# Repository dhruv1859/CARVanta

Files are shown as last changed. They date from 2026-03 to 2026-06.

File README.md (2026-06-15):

<p align="center">
  
</p>

<h1 align="center">🧬 CARVanta</h1>
<h3 align="center">AI-Augmented CAR-T Cell Target Viability Assessment Platform<br>+ Sentinel HYDRA Bedside Biosensor</h3>

<p align="center">
  
  
  
  
  
  
</p>

<p align="center">
  
  
  
  
  
</p>

<p align="center">
  <strong>117,000+ lines of code • 778 source files • 214 Python modules • 45 React pages • 50 firmware files • 6-layer medical PCB</strong>
</p>

---

## 🎯 What is CARVanta?

**CARVanta** is a closed-loop immunotherapy intelligence system — an **AI software platform** connected to a **bedside biosensor device** — that turns CAR-T cell therapy target selection from art into science.

> **The core problem:** Selecting the right antigen target is the most critical decision in CAR-T therapy design. A wrong target leads to years of wasted R&D and patient harm. CARVanta automates this decision with data-driven scoring validated against FDA-approved targets, and monitors treatment in real time to catch antigen escape before it kills.

### Key Capabilities

| Module | Description |
|---|---|
| 🔬 **CVS Scoring Engine** | 8-feature adaptive weighted algorithm with multi-source consensus |
| 🤖 **ML Ensemble** | Random Forest + XGBoost classifier + regression ranker |
| 🧠 **LLM Integration** | Grok/Groq/Gemini/OpenAI for dynamic clinical reasoning |
| 🧬 **Genomic Profiler** | Variant calling, HLA typing, TMB calculation, neoantigen prediction |
| 🧑‍⚕️ **Digital Twin** | Patient-specific CRS/ICANS simulation with pharmacokinetic modeling |
| 📊 **Clinical Trials** | Safety monitoring, DSMB reports, RWE analysis, regulatory intelligence |
| 🔍 **NLP Search** | Natural language antigen discovery with semantic intent detection |
| 🏆 **Model Validation** | 5-fold CV, FDA ground-truth validation, ISO/IEC 25010 certification |
| 🌐 **Neural Bridge** | 3D knowledge graph visualization of antigen-disease relationships |
| 💊 **Drug Discovery** | scFv designer, toxicity prediction, CAR construct architecture |
| 📈 **Deep Learning** | Autoencoder anomaly detection, attention mechanisms, neural scoring |
| 🔬 **Sentinel HYDRA** | Real-time 4-channel antigen monitoring with bedside biosensor hardware |

---

## 🏗️ Architecture

```
Patient blood (fingerprick)
        │
        ▼
┌───────────────────────┐
│   SENTINEL HYDRA      │     Bedside device — 100×100mm, ~$79/unit
│   RP2040 + ESP32-S3   │     6-layer medical PCB, ENIG finish
│                       │
│   • 4× potentiostat   │     Sensor data
│   • SpO2 + heart rate │     ─────────────────►
│   • 11-ch spectral    │          WiFi (TLS)
│   • Impedance + temp  │
└───────────┬───────────┘
            │
            ▼
┌─────────────────────────────────────────────────────────────┐
│                    CARVANTA CLOUD PLATFORM                    │
├─────────────────────────────────────────────────────────────┤
│                    Frontend (React + Vite)                    │
│  45 pages • Clinical Precision UI • Glassmorphism Design     │
├─────────────────────────────────────────────────────────────┤
│                    FastAPI Backend (v5)                       │
│  28 routers • Async • CORS • Rate limiting • Audit logging   │
├──────────┬──────────┬──────────┬──────────┬─────────────────┤
│ Scoring  │    ML    │   LLM    │ Genomics │   Validation    │
│ Engine   │ Ensemble │ Insight  │ Pipeline │   & Certify     │
│ (CVS v3) │ (RF+XGB) │(Grok/AI) │(VCF/HLA)│  (ISO 25010)   │
├──────────┴──────────┴──────────┴──────────┴─────────────────┤
│              Data Layer (SQLite / PostgreSQL)                 │
│        biomarker_database.csv • 500+ scored antigens         │
└─────────────────────────────────────────────────────────────┘
            │
            ▼
  Doctor's phone: "CD19 dropping — antigen escape risk. Switch to CD22."
```

> For a deep dive into the full system architecture, see [ARCHITECTURE.md](ARCHITECTURE.md).

---

## 🔬 Sentinel HYDRA — Bedside Biosensor

The **Sentinel HYDRA** is a credit-card-sized medical-grade device that continuously monitors blood biomarkers through a disposable sensor strip. It detects antigen escape — the #1 reason CAR-T fails — in **30 seconds** instead of days via lab tests.

### Hardware Specifications

| Parameter | Value |
|---|---|
| Dimensions | 100mm × 100mm |
| PCB Layers | **6** (signal/ground/analog/power/high-speed/bottom) |
| MCUs | **ESP32-S3** (main) + **RP2040** (sensor coprocessor) |
| Antigen Channels | **4 simultaneous** (CD19, CD22, BCMA, GPRC5D) |
| ADC | ADS1256 — **24-bit**, 8-channel, 30kSPS |
| Potentiostat | 4× LMP91000 (one per antigen channel) |
| SpO2/Heart Rate | MAX30102 integrated sensor |
| Spectral | AS7341 — **11 wavelength channels** |
| Temperature | TMP117 (±0.1°C) + MLX90614 (contactless IR) |
| IMU | LSM6DSO — 6-axis (fall detection) |
| Display | 2.4" IPS TFT (320×240, ST7789) |
| Connectivity | WiFi + BLE (ESP32-S3) |
| Data Logging | microSD + DS3231 RTC |
| Power | USB-C + LiPo battery (BQ24075 charger) |
| Surface Finish | ENIG (immersion gold) — biocompatible |
| Cost per Unit | **~$79** (complete with battery + display + sensor) |

### Manufacturing Files

Production-ready Gerber files for PCB fabrication are available:

📦 **[Sentinel_HYDRA_Gerbers.zip](hardware/sentinel/kicad/Sentinel_HYDRA/Sentinel_HYDRA_Gerbers.zip)** — Upload directly to JLCPCB / PCBWay

Contains:
- 6 copper layers (Digital_Signals, GND_Plane, Analog_Signals, Power_Planes, HighSpeed, Bottom_GND)
- Front/Back solder mask, silkscreen, paste stencil
- Board outline (Edge.Cuts)
- Excellon drill files (PTH + NPTH separated)
- Drill map files
- Gerber job file

> For the full Bill of Materials, see [BOM.md](hardware/sentinel/BOM.md).

---

## 🚀 Quick Start

### Prerequisites

- Python 3.12+
- Node.js 18+
- Git

### 1. Clone & Setup

```bash
git clone https://github.com/dhruv1859/CARVanta.git
cd CARVanta

# Backend
pip install -r requirements.txt
copy .env.example .env
# Edit .env — add your XAI_API_KEY or GROQ_API_KEY for LLM features

# Frontend
cd frontend-react
npm install
```

### 2. Run Locally

```bash
# Terminal 1 — Backend
py -m uvicorn api.main:app --host 0.0.0.0 --port 8001

# Terminal 2 — Frontend
cd frontend-react
npm run dev
```

Open **http://localhost:5173** → full platform is live.

### 3. Train ML Models (Optional)

```bash
py models/train_pipeline.py
```

This runs 5-fold stratified cross-validation and trains the RF+XGBoost ensemble + regression ranker.

### 4. Build Firmware (Optional)

Requires [PlatformIO](https://platformio.org/install):

```bash
# ESP32 main controller
cd hardware/sentinel/firmware/esp32_hydra
pio run

# RP2040 sensor coprocessor
cd hardware/sentinel/firmware/rp2040_hydra
pio run
```

---

## 🧪 Scoring Algorithm

### CVS (CAR-T Viability Score) v3

CARVanta's **original** 8-feature Adaptive Weighted Scoring:

| Feature | Weight | Source |
|---|---|---|
| Tumor Specificity | 25% | TCGA differential expression |
| Safety Score | 20% | GTEx normal tissue risk (inverted) |
| Stability | 12% | Expression consistency |
| Evidence | 10% | Published clinical support |
| Immunogenicity | 10% | Immune recognition potential |
| Surface Accessibility | 8% | UniProt/HPA membrane localization |
| Tissue Risk | 8% | GTEx organ-level heatmap |
| Protein Validation | 7% | HPA protein-level confirmation |

**Adaptive Weight Adjustment:** When real data sources (TCGA, GTEx, HPA) are available, feature weights dynamically shift to give more credence to features backed by real data vs. estimated values.

### ML Ensemble (v4)

The final score blends rule-based CVS with ML predictions:

```
Adaptive Score = (1 - α) × CVS + α × ML_score
```

Where `α` is dynamically adjusted based on data confidence (range: 0.20–0.40).

---

## 🏆 Model Validation & Certification

CARVanta includes a **production-grade validation suite** aligned with ISO/IEC 25010:

| Test | Method | What It Proves |
|---|---|---|
| **Classifier CV** | 5-fold Stratified K-Fold | Accuracy, F1, AUC-ROC, Precision, Recall |
| **Ranker CV** | 5-fold K-Fold Regression | R², MAE, RMSE, Spearman ρ |
| **FDA Ground-Truth** | CD19, BCMA, CD22, GPRC5D | All approved targets must score Tier 1 |
| **Negative Controls** | TP53, RB1, BRCA1, PTEN, APC | Non-viable targets rejected correctly |
| **Robustness** | ±5% feature perturbation | Measures prediction stability |
| **Statistical Significance** | Paired t-test + Wilcoxon | Model vs. 3 random baselines (p < 0.01) |
| **Calibration** | Brier score + log loss | Probability reliability |

Run validation: `GET /api/v5/validation/run`

---

## 🤖 LLM Integration

CARVanta uses LLMs to generate **dynamic clinical reasoning** instead of hardcoded insights:

- **Supported Providers:** Grok (xAI) → Groq → DeepSeek → Gemini → OpenAI
- **Fallback:** If no LLM key is configured, rule-based insights are served
- **Provenance:** Every AI insight displays a badge showing `🤖 LLM Generated` or `📐 Rule-Based`

Set one key in `.env`:
```
XAI_API_KEY=your-grok-key
# or
GROQ_API_KEY=your-groq-key
```

---

## ☁️ Deploy to Railway

### One-Click Deploy

1. Go to [railway.app](https://railway.app) → **New Project** → **Deploy from GitHub repo**
2. Select `dhruv1859/CARVanta`
3. Railway auto-detects `nixpacks.toml` and builds
4. Add environment variables in Railway dashboard:

| Variable | Required | Description |
|---|---|---|
| `XAI_API_KEY` | ✅ | Grok API key for LLM insights |
| `CARVANTA_ENV` | Optional | Set to `production` |
| `DATABASE_URL` | Optional | PostgreSQL URL (defaults to SQLite) |

5. Railway assigns a public URL → your API is live

### Frontend Deployment

Deploy the React frontend separately on **Vercel** or **Netlify**:

```bash
cd frontend-react
npm run build
# Upload dist/ to Vercel/Netlify
# Set VITE_API_URL to your Railway backend URL
```

---

## 📁 Project Structure

```
CARVanta/
├── api/                        # 28 FastAPI routers (v5)
│   ├── main.py                 # App entrypoint
│   ├── auth.py                 # JWT authentication
│   ├── validation_router.py    # Model validation endpoints
│   └── ...
├── scoring/                    # CVS scoring engine (v3)
├── models/                     # ML pipeline (RF + XGBoost)
├── features/                   # Feature engineering + LLM + FHIR
├── validation/                 # Model validation & certification
├── deep_learning/              # Autoencoder, attention, neural models
├── genomics/                   # Variant calling, HLA, TMB
├── digital_twin/               # Patient simulation engine
├── discovery/                  # Drug discovery, scFv design
├── copilot/                    # Research assistant, RAG engine
├── trials/                     # Clinical trial intelligence
├── frontend-react/             # React 18 + Vite + TypeScript
│   └── src/pages/              # 45 page modules
├── hardware/
│   └── sentinel/
│       ├── kicad/
│       │   └── Sentinel_HYDRA/         # 6-layer KiCad PCB project
│       │       ├── *.kicad_sch         # 7 schematic sheets
│       │       ├── Sentinel_HYDRA.kicad_pcb
│       │       ├── gerbers/            # Production Gerber files
│       │       └── Sentinel_HYDRA_Gerbers.zip
│       ├── firmware/
│       │   ├── esp32_hydra/            # ESP32-S3 firmware (50 files)
│       │   └── rp2040_hydra/           # RP2040 firmware
│       ├── BOM.md                      # Bill of materials (~$79/unit)
│       └── README.md                   # Hardware documentation
├── data/                       # Biomarker database + reports
├── ARCHITECTURE.md             # Full system architecture
├── nixpacks.toml               # Railway deployment config
├── railway.json                # Railway service config
└── requirements.txt            # Python dependencies
```

---

## 🔑 API Endpoints

### Core Scoring
| Endpoint | Method | Description |
|---|---|---|
| `/api/v5/score` | POST | Score a single antigen |
| `/api/v5/batch_score` | POST | Score multiple antigens |
| `/api/v5/rankings` | GET | Global antigen leaderboard |
| `/api/v5/nlp/query` | POST | Natural language search |

### Validation
| Endpoint | Method | Description |
|---|---|---|
| `/api/v5/validation/run` | GET | Full validation suite |
| `/api/v5/validation/quick` | GET | Quick classifier + FDA check |
| `/api/v5/validation/fda-targets` | GET | FDA ground-truth only |
| `/api/v5/validation/certification` | GET | ISO/IEC 25010 report |

### Clinical
| Endpoint | Method | Description |
|---|---|---|
| `/api/v5/digital-twin/simulate` | POST | Patient simulation |
| `/api/v5/trials/clinical-trials` | GET | Trial lookup by antigen |
| `/api/v5/genomics/analyze-variants` | POST | Genomic variant analysis |

Full API docs: `http://localhost:8001/docs` (Swagger UI)

---

## 🛡️ Security & Compliance

- **ISO/IEC 25010** aligned model validation and certification
- **FDA 21 CFR Part 11** concepts for electronic records
- **GAMP 5** risk-based approach compliance framework
- **LLM Provenance** — all AI outputs labeled with origin (LLM vs Rule-Based)
- **Audit Logging** — all scoring requests logged with timestamps
- **CORS + Rate Limiting** middleware (configurable)

See [security.md](security.md) for vulnerability reporting and [PRIVACY_POLICY.md](PRIVACY_POLICY.md) for HIPAA alignment.

---

## 📄 Documentation

| Document | Description |
|---|---|
| [ARCHITECTURE.md](ARCHITECTURE.md) | Full system architecture (software + hardware + firmware) |
| [BOM.md](hardware/sentinel/BOM.md) | Sentinel HYDRA bill of materials |
| [ROADMAP.md](ROADMAP.md) | Product roadmap and future plans |
| [MODULES.md](MODULES.md) | Module registry and build order |
| [CHANGELOG.md](CHANGELOG.md) | Version history |
| [contributing.md](contributing.md) | Contribution guidelines |
| [security.md](security.md) | Security policy |
| [CODE_OF_CONDUCT.md](CODE_OF_CONDUCT.md) | Community code of conduct |
| [MODEL_CARD.md](MODEL_CARD.md) | ML model documentation |
| [ISO_13485_ALIGNMENT.md](ISO_13485_ALIGNMENT.md) | Quality management alignment |
| [PRIVACY_POLICY.md](PRIVACY_POLICY.md) | HIPAA compliance disclosure |

---

## 📄 License

Business Source License 1.1 (BUSL-1.1). See [LICENSE](LICENSE) for details.

---

## 👨‍💻 Author

**Dhruv** — [@dhruv1859](https://github.com/dhruv1859)

---

<p align="center">
  <strong>CARVanta</strong> — Turning immunotherapy target selection from art into science.
</p>

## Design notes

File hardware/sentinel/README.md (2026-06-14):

# CARVanta Sentinel v2.0 — 6-Layer Medical-Grade PCB
## Multi-Channel Antigen Escape Detection System

### Why 6 Layers?

This board monitors **4 antigens simultaneously** (CD19, CD22, BCMA, GPRC5D),
meaning 4 independent electrochemical channels that MUST be electrically isolated
from each other and from the digital noise of the ESP32 + WiFi radio.

A 2-layer board cannot achieve this. Here's why each layer exists:

```
Layer 1 (F.Cu)  — Digital signals: SPI, I2C, UART, USB, GPIO
Layer 2 (GND)   — Continuous ground plane (EMI shield between digital & analog)
Layer 3 (INNER1)— Analog signals: 4× potentiostat outputs, ADC inputs, sensor traces
Layer 4 (PWR)   — Power planes: 3.3V_DIGITAL, 3.3V_ANALOG, 1.8V_CORE, VBAT
Layer 5 (INNER2)— High-speed: USB 2.0 differential pair, WiFi RF routing
Layer 6 (B.Cu)  — Component pads, ground pour, thermal relief
```

### Board Specifications

| Parameter | v1.0 (old) | v2.0 (new) |
|---|---|---|
| Dimensions | 80×55mm | 95×65mm |
| Layers | 2 | **6** |
| Channels | 1 antigen | **4 simultaneous** |
| ADC | 1× ADS1115 (16-bit) | **1× ADS1256 (24-bit, 8ch)** |
| Potentiostat | 1× LMP91000 | **4× LMP91000** |
| Power domains | 1 (3.3V) | **4 (3.3V_D, 3.3V_A, 1.8V, VBAT)** |
| Analog isolation | None | **Split ground plane + ferrite bead** |
| Data logging | None | **microSD + RTC** |
| Patient vitals | None | **MAX30102 SpO2/HR + MLX90614 temp** |
| Impedance control | No | **90Ω USB, 50Ω RF** |
| ESD protection | No | **TVS diodes on all I/O** |
| Cost per unit | $17 | **~$45-55** |

### Stackup (6-Layer, 1.6mm FR4)

```
┌─────────────────────────────────────────────────────────┐
│ Layer 1: F.Cu (Signal - Digital)          35µm copper   │
│   └─ SPI bus, I2C bus, UART, GPIO, LED data            │
├─────────────────────────────────────────────────────────┤
│ Prepreg: 0.2mm FR4 (εr=4.5)                            │
├─────────────────────────────────────────────────────────┤
│ Layer 2: GND (Solid Ground Plane)         35µm copper   │
│   └─ Continuous pour, NO cuts, NO traces                │
│   └─ Acts as EMI shield between digital L1 & analog L3 │
├─────────────────────────────────────────────────────────┤
│ Core: 0.36mm FR4                                        │
├─────────────────────────────────────────────────────────┤
│ Layer 3: INNER1 (Signal - Analog)         35µm copper   │
│   └─ 4× LMP91000 VOUT traces (guarded)                 │
│   └─ ADS1256 analog inputs (star routing)               │
│   └─ Sensor connector traces (kelvin connection)        │
├─────────────────────────────────────────────────────────┤
│ Prepreg: 0.2mm FR4                                      │
├─────────────────────────────────────────────────────────┤
│ Layer 4: PWR (Power Planes)               35µm copper   │
│   └─ Zone 1: 3.3V_DIGITAL (ESP32, TFT, LEDs)          │
│   └─ Zone 2: 3.3V_ANALOG (LMP91000s, ADS1256)         │
│   └─ Zone 3: VBAT (battery direct)                      │
│   └─ Zone 4: 1.8V (ESP32 core, if needed)              │
├─────────────────────────────────────────────────────────┤
│ Core: 0.36mm FR4                                        │
├─────────────────────────────────────────────────────────┤
│ Layer 5: INNER2 (High-Speed Signals)      35µm copper   │
│   └─ USB D+/D- differential pair (90Ω impedance)       │
│   └─ ESP32 antenna feed (50Ω microstrip)                │
│   └─ SD card high-speed data lines                      │
├─────────────────────────────────────────────────────────┤
│ Prepreg: 0.2mm FR4                                      │
├─────────────────────────────────────────────────────────┤
│ Layer 6: B.Cu (Signal + Ground Pour)      35µm copper   │
│   └─ Component pads (bottom-side ICs)                   │
│   └─ Ground pour for thermal dissipation                │
│   └─ Mounting hole connections                          │
└─────────────────────────────────────────────────────────┘
Total thickness: ~1.6mm
```

### Design Rules (Medical Grade)

| Rule | Value | Reason |
|---|---|---|
| Min trace width | 0.15mm (6mil) | JLCPCB 6-layer capability |
| Min clearance | 0.15mm | IPC-2221 Class 2 |
| USB diff pair | 0.18mm trace, 0.15mm gap | 90Ω impedance on L5 |
| Analog traces | 0.25mm, guarded | Noise rejection |
| Power traces | 0.5mm minimum | Current handling |
| Via size | 0.3mm drill, 0.6mm pad | Standard via |
| Via-in-pad | Allowed (filled & capped) | For QFN packages |
| Copper weight | 1oz (35µm) all layers | Standard |
| Surface finish | ENIG (gold) | Corrosion resistance, biocompat |
| Solder mask | Matte black | Premium aesthetic |
| Silkscreen | White, both sides | Component labels |

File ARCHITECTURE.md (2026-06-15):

# CARVanta — System Architecture

> Comprehensive technical architecture of the CARVanta AI Immunotherapy Platform and Sentinel HYDRA biosensor hardware.

---

## System Overview

CARVanta is a **closed-loop immunotherapy intelligence system** comprising two tightly integrated subsystems:

1. **Software Platform** — Cloud-deployed AI engine for antigen target scoring, genomic analysis, digital twin simulation, and clinical decision support
2. **Sentinel HYDRA** — Bedside biosensor hardware for real-time multi-channel antigen monitoring with cloud telemetry

```
┌─────────────────────────────────────────────────────────────────────────────┐
│                         PATIENT INTERFACE                                    │
│                                                                              │
│   [Fingerprick Blood Sample]  ──►  [Disposable Sensor Strip]                │
│                                            │                                 │
│                                            ▼                                 │
│   ┌──────────────────────────────────────────────────────────┐              │
│   │              SENTINEL HYDRA (Bedside Device)              │              │
│   │                                                           │              │
│   │   RP2040 ◄──UART──► ESP32-S3                             │              │
│   │   • 4× LMP91000      • WiFi/BLE                          │              │
│   │   • ADS1256 24-bit    • TFT Display                      │              │
│   │   • AS7341 Spectral   • SD Logging                       │              │
│   │   • TMP117/MLX90614   • Cloud Upload                     │              │
│   │   • MAX30102 SpO2     • OTA Updates                      │              │
│   └──────────────┬───────────────────────────────────────────┘              │
│                  │ WiFi (TLS 1.2+)                                           │
│                  ▼                                                           │
│   ┌──────────────────────────────────────────────────────────┐              │
│   │           CARVANTA CLOUD PLATFORM                         │              │
│   │                                                           │              │
│   │   FastAPI Backend ◄──REST──► React Frontend               │              │
│   │   • CVS Scoring Engine       • 45 UI Pages                │              │
│   │   • ML Ensemble (RF+XGB)     • Clinical Precision UI      │              │
│   │   • LLM Integration          • Real-time Dashboards       │              │
│   │   • Digital Twin Engine      • Genomic Profiler           │              │
│   │   • Genomic Pipeline         • 3D Neural Bridge           │              │
│   │   • Trial Matcher            • Report Generator           │              │
│   └──────────────┬───────────────────────────────────────────┘              │
│                  │                                                           │
│                  ▼                                                           │
│   [Doctor's Dashboard] ──► [Alert: "CD19 dropping — escape risk"]           │
└─────────────────────────────────────────────────────────────────────────────┘
```

---

## Software Architecture

### Technology Stack

| Layer | Technology | Version |
|---|---|---|
| Backend | Python + FastAPI | 3.12+ / 0.104+ |
| Frontend | React + Vite + TypeScript | 18 / 5.x |
| ML Models | scikit-learn + XGBoost | 1.3 / 2.0 |
| Deep Learning | PyTorch (autoencoder, attention) | 2.x |
| LLM Integration | Grok / Groq / Gemini / OpenAI | Multi-provider |
| Database | SQLite (dev) / PostgreSQL (prod) | — |
| Deployment | Railway (backend) + Vercel (frontend) | — |

### Backend Architecture

```
api/
├── main.py                    # FastAPI app entrypoint (v5)
├── auth.py                    # JWT + PBKDF2 authentication
├── auth_router.py             # Auth endpoints (register, login, profile)
├── validation_router.py       # Model validation + certification
├── deep_learning_router.py    # Autoencoder + neural scoring
├── genomics_router.py         # Variant calling, HLA, TMB
├── digital_twin_router.py     # Patient simulation
├── trials_router.py           # Clinical trial intelligence
├── audit_logger.py            # HIPAA-aligned audit middleware
└── ... (28 routers total)

scoring/                        # CVS v3 Scoring Engine
├── cvs_engine.py              # 8-feature adaptive weighted scoring
├── adaptive_weights.py        # Dynamic weight adjustment
└── tier_classifier.py         # Score → Tier mapping

models/                         # ML Pipeline
├── train_pipeline.py          # 5-fold CV training
├── car_t_model.pkl            # Random Forest classifier
└── car_t_ranker.pkl           # XGBoost regression ranker

features/                       # Feature Engineering + Services
├── tumor_features.py          # TCGA/GTEx/HPA feature generation
├── llm_insight.py             # Multi-provider LLM integration
├── explainability.py          # SHAP-based feature attribution
├── drug_interactions.py       # Drug-antigen interaction checker
├── fhir_export.py             # HL7 FHIR R4 diagnostic reports
└── notation_standards.py      # HUGO/NCBI/UniProt gene mappings
```

### Scoring Pipeline

```
Input: Antigen Name (e.g., "CD19")
         │
         ▼
┌──────────────────────┐
│  Feature Generation  │ ◄── TCGA, GTEx, HPA, ClinicalTrials.gov
│  (8 dimensions)      │
└──────────┬───────────┘
           │
     ┌─────┴─────┐
     ▼           ▼
┌─────────┐ ┌─────────┐
│ CVS v3  │ │   ML    │
│ Rule-   │ │ RF+XGB  │
│ Based   │ │ Trained │
└────┬────┘ └────┬────┘
     │           │
     ▼           ▼
┌──────────────────────┐
│   Adaptive Blend     │
│ Score = (1-α)·CVS    │
│       + α·ML_score   │
│ α = 0.20 – 0.40      │
└──────────┬───────────┘
           │
           ▼
┌──────────────────────┐
│  Tier Classification │
│  Tier 1: ≥ 75        │
│  Tier 2: 50–74       │
│  Tier 3: < 50        │
└──────────┬───────────┘
           │
           ▼
┌──────────────────────┐
│  LLM Clinical        │ ◄── Grok → Groq → DeepSeek (fallback chain)
│  Reasoning           │
└──────────────────────┘
```

### CVS Feature Weights

| Feature | Weight | Data Source |
|---|---|---|
| Tumor Specificity | 25% | TCGA differential expression |
| Safety Score | 20% | GTEx normal tissue risk (inverted) |
| Stability | 12% | Expression consistency across samples |
| Evidence | 10% | Published clinical trial support |
| Immunogenicity | 10% | Immune recognition potential |
| Surface Accessibility | 8% | UniProt/HPA membrane localization |
| Tissue Risk | 8% | GTEx organ-level heatmap |
| Protein Validation | 7% | HPA protein-level confirmation |

### Frontend Architecture

```
frontend-react/
├── src/
│   ├── pages/              # 45 page modules
│   │   ├── Dashboard.tsx           # Main scoring dashboard
│   │   ├── SingleAnalysis.tsx      # Deep-dive single antigen
│   │   ├── GenomicProfiler.tsx     # Genomic variant analysis
│   │   ├── DigitalTwin.tsx         # Patient simulation
│   │   ├── NeuralBridge.tsx        # 3D knowledge graph
│   │   ├── DrugInteractions.tsx    # Drug-antigen interactions
│   │   ├── ClinicalTrials.tsx      # Trial matcher
│   │   └── ...
│   ├── context/
│   │   └── AuthContext.tsx         # Authentication state
│   ├── styles/                     # CSS modules
│   └── App.tsx                     # Root with routing
├── vite.config.ts
└── package.json
```

### API Architecture

- **28 routers** serving **30+ endpoints** under `/api/v5/`
- Async request handling with FastAPI
- CORS middleware with configurable allowed origins
- Rate limiting per endpoint
- Audit logging middleware for HIPAA compliance
- Swagger UI auto-generated at `/docs`

---

## Hardware Architecture — Sentinel HYDRA

### Physical Specifications

| Parameter | Value |
|---|---|
| Board Dimensions | 95mm × 65mm |
| Layer Count | 6 (signal/ground/analog/power/high-speed/bottom) |
| Thickness | 1.6mm FR4 |
| Surface Finish | ENIG (Immersion Gold) |
| Solder Mask | Matte Black |
| Components | 135 (123 SMD + 11 THT + 1 unspecified) |
| Vias | 225 through-hole |
| Pads | 641 SMD + 72 through-hole + 9 NPTH |
| Cost per Unit | ~$79 (complete with battery + display + sensor) |

### PCB Layer Stackup

```
┌─────────────────────────────────────────────────────────────┐
│ Layer 1 (F.Cu) — "Digital_Signals"            35µm copper   │
│   SPI, I2C, UART, GPIO, LED data, display interface        │
├─────────────────────────────────────────────────────────────┤
│ Prepreg: 0.2mm FR4 (εr=4.5)                                │
├─────────────────────────────────────────────────────────────┤
│ Layer 2 (In1.Cu) — "GND_Plane"               35µm copper   │
│   Continuous ground pour — EMI shield (digital ↔ analog)    │
├─────────────────────────────────────────────────────────────┤
│ Core: 0.36mm FR4                                            │
├─────────────────────────────────────────────────────────────┤
│ Layer 3 (In2.Cu) — "Analog_Signals"          35µm copper   │
│   4× LMP91000 outputs, ADS1256 inputs, sensor traces       │
├─────────────────────────────────────────────────────────────┤
│ Prepreg: 0.2mm FR4                                          │
├─────────────────────────────────────────────────────────────┤
│ Layer 4 (In3.Cu) — "Power_Planes"            35µm copper   │
│   3.3V_DIGITAL, 3.3V_ANALOG, 1.8V_CORE, VBAT              │
├─────────────────────────────────────────────────────────────┤
│ Core: 0.36mm FR4                                            │
├─────────────────────────────────────────────────────────────┤
│ Layer 5 (In4.Cu) — "HighSpeed"               35µm copper   │
│   USB D+/D- (90Ω), ESP32 antenna (50Ω), SD card data       │
├─────────────────────────────────────────────────────────────┤
│ Prepreg: 0.2mm FR4                                          │
├─────────────────────────────────────────────────────────────┤
│ Layer 6 (B.Cu) — "Bottom_GND"                35µm copper   │
│   Component pads, ground pour, thermal relief               │
└─────────────────────────────────────────────────────────────┘
Total thickness: ~1.6mm
```

### Dual-MCU Architecture

The Sentinel HYDRA uses a **dual-processor architecture** to separate real-time sensor acquisition from application-level processing:

```
┌──────────────────────────────┐     UART (921600 baud)     ┌──────────────────────────────┐
│         RP2040               │ ◄────────────────────────► │         ESP32-S3             │
│   (Sensor Coprocessor)       │                             │   (Main Controller)          │
│                              │                             │                              │
│ • 4× LMP91000 potentiostat   │   Sensor data packets      │ • WiFi + BLE radio           │
│ • ADS1256 24-bit ADC         │   ──────────────────►       │ • 2.4" TFT display (ST7789)  │
│ • AS7341 11-ch spectral      │                             │ • microSD data logging       │
│ • TMP117 temperature         │   Commands + config         │ • Cloud client (HTTPS)       │
│ • MAX30102 SpO2/HR           │   ◄──────────────────       │ • OTA firmware updates       │
│ • Impedance measurement      │                             │ • User interface + alerts    │
│ • PID heater control         │                             │ • Power management           │
│ • LSM6DSO IMU                │                             │ • DS3231 RTC                 │
│                              │                             │                              │
│ Priority: Deterministic      │                             │ Priority: Connectivity       │
│           real-time sampling │                             │           + user experience   │
└──────────────────────────────┘                             └──────────────────────────────┘
```

### I2C Bus Topology

```
ESP32-S3 (I2C Master)
    │
    ├── TCA9548A I2C Multiplexer (U14, addr: 0x70)
    │       ├── Ch0: LMP91000 #1 (0x48) — Antigen Channel 1
    │       ├── Ch1: LMP91000 #2 (0x48) — Antigen Channel 2
    │       ├── Ch2: LMP91000 #3 (0x48) — Antigen Channel 3
    │       ├── Ch3: LMP91000 #4 (0x48) — Antigen Channel 4
    │       └── Ch4: MAX30102 (0x57) — SpO2 / Heart Rate
    │
    ├── DS3231 RTC (0x68) — Timestamping
    ├── MAX17048 Fuel Gauge (0x36) — Battery SOC
    └── MLX90614 IR Temp (0x5A) — Contactless temperature

RP2040 (I2C Master — separate bus)
    │
    ├── TMP117 (0x48) — Precision temperature
    ├── AS7341 (0x39) — 11-channel spectral sensor
    └── LSM6DSO (0x6A) — Accelerometer + gyroscope
```

### SPI Bus Sharing

```
ESP32-S3 SPI Bus (VSPI)
    │
    ├── GPIO2  (CS) ──► ADS1256 24-bit ADC
    ├── GPIO8  (CS) ──► ST7789 TFT Display
    └── GPIO14 (CS) ──► microSD Card
    
    Shared lines:
    • GPIO11 — MOSI
    • GPIO12 — SCK
    • GPIO13 — MISO
```

### Power Architecture

```
USB-C (5V) or LiPo Battery (3.7V)
    │
    ├── BQ24075 (U3) — Battery charger + power path management
    │       │
    │       ├── MAX17048 (U7) — Battery fuel gauge (I2C)
    │       └── BQ29700 (U8) — Battery protection (OVP/UVP/OCP)
    │
    ├── TPS7A2033 (U4) ──► 3.3V_DIGITAL
    │       └── ESP32-S3, TFT, LEDs, SD card, digital ICs
    │
    ├── TPS7A4533 (U5) ──► 3.3V_ANALOG
    │       └── LMP91000s, ADS1256, analog sensors
    │
    ├── AP2112K-1.8 (U6) ──► 1.8V_CORE
    │       └── ESP32 core (optional)
    │
    └── Ferrite bead (L1) — AGND ↔ DGND bridge
            └── Single-point ground connection
```

### Sensor Subsystems

| Subsystem | Sensors | Channels | Resolution | Interface |
|---|---|---|---|---|
| Electrochemical | 4× LMP91000 + ADS1256 | 4 antigens | 24-bit | I2C (muxed) + SPI |
| Optical/Spectral | AS7341 | 11 wavelengths | 16-bit | I2C |
| Pulse Oximetry | MAX30102 | SpO2 + HR | 18-bit | I2C |
| Temperature | TMP117 + MLX90614 | Ambient + IR | 16-bit | I2C |
| Motion/Fall | LSM6DSO | 6-axis IMU | 16-bit | I2C |
| Impedance | Custom analog front-end | Cell health | 24-bit (ADC) | Analog |

---

## Firmware Architecture

### ESP32-S3 Firmware (`firmware/esp32_hydra/`)

```
src/
├── main.cpp              # Boot sequence, task orchestration, FreeRTOS
├── config.h              # System-wide configuration constants
├── pins.h                # GPIO assignments (all 30+ pins)
├── comms/
│   ├── cloud_client.cpp/h    # HTTPS POST to CARVanta cloud API
│   ├── wifi_manager.cpp/h    # WiFi provisioning + reconnection
│   └── uart_bridge.cpp/h     # RP2040 ↔ ESP32 packet protocol
├── sensors/
│   ├── lmp91000.cpp/h        # Potentiostat driver (4-channel muxed)
│   ├── max30102.cpp/h        # SpO2 + heart rate sensor
│   ├── ds3231.cpp/h          # Real-time clock
│   ├── lsm6dso.cpp/h         # IMU (fall detection)
│   └── mlx90614.cpp/h        # Contactless IR temperature
├── storage/
│   ├── sd_logger.cpp/h       # SD card CSV data logging
│   └── config_store.cpp/h    # NVS persistent settings
├── system/
│   ├── power_manager.cpp/h   # Sleep modes, battery monitoring
│   └── ota_updater.cpp/h     # Over-the-air firmware updates
└── ui/
    ├── display.cpp/h         # ST7789 TFT rendering
    ├── led_status.cpp/h      # WS2812B status LEDs
    └── buzzer.cpp/h          # Audio alerts
```

### RP2040 Firmware (`firmware/rp2040_hydra/`)

```
src/
├── main.cpp              # Sensor loop, timer interrupts, UART TX
├── config.h              # Sampling rates, calibration constants
├── pins.h                # RP2040 GPIO assignments
├── drivers/
│   ├── ads1256.cpp/h         # 24-bit ADC driver (SPI, 30kSPS)
│   ├── as7341.cpp/h          # 11-channel spectral sensor
│   ├── tmp117.cpp/h          # ±0.1°C precision temperature
│   └── impedance.cpp/h       # Impedance spectroscopy front-end
├── control/
│   ├── pid_heater.cpp/h      # PID temperature controller
│   ├── led_driver.cpp/h      # Sensor excitation LEDs
│   └── calibration.cpp/h     # Auto-calibration routines
└── comms/
    └── uart_protocol.cpp/h   # Packet framing + CRC for ESP32 link
```

### Inter-MCU Communication Protocol

```
Packet Format (UART @ 921600 baud):
┌──────┬──────┬────────┬───────────────┬───────┬──────┐
│ SYNC │ TYPE │ LENGTH │    PAYLOAD    │  CRC  │ END  │
│ 0xAA │ 1B   │  2B    │  0–512 bytes  │  2B   │ 0x55 │
└──────┴──────┴────────┴───────────────┴───────┴──────┘

Message Types:
  0x01 — Electrochemical data (4× antigen levels)
  0x02 — Spectral data (11 channels)
  0x03 — Temperature data (ambient + IR)
  0x04 — SpO2 + heart rate
  0x05 — Impedance measurement
  0x06 — IMU data (accelerometer + gyro)
  0x10 — Config update (ESP32 → RP2040)
  0x11 — Calibration command
  0xFF — Error / status report
```

---

## Data Flow

### Measurement Cycle (30 seconds)

```
1. RP2040 initiates sensor scan
   ├── Potentiostat sweep (4 channels × 200 points)
   ├── Spectral acquisition (11 channels)
   ├── Temperature reading (TMP117 + MLX90614)
   └── Impedance measurement

2. RP2040 → ESP32 via UART
   └── Packetized sensor data with CRC

3. ESP32 processes + displays
   ├── TFT display update (real-time waveforms)
   ├── SD card logging (timestamped CSV)
   ├── Local anomaly detection
   └── WS2812B status LED update

4. ESP32 → CARVanta Cloud via WiFi
   ├── HTTPS POST to /api/v5/sentinel/upload
   ├── Payload: JSON with all sensor readings
   └── Response: AI analysis + alerts

5. Cloud processes + alerts
   ├── Trend analysis (antigen escape detection)
   ├── Digital twin update
   ├── Doctor notification (if thresholds exceeded)
   └── Dashboard update (real-time)
```

---

## Deployment Architecture

```
┌─────────────────────┐      ┌─────────────────────┐
│   Railway            │      │   Vercel / Netlify   │
│   (Backend)          │      │   (Frontend)         │
│                      │      │                      │
│   FastAPI + Uvicorn  │◄────►│   React + Vite       │
│   SQLite / PG        │ REST │   Static SPA         │
│   ML Models (.pkl)   │      │   VITE_API_URL       │
│                      │      │                      │
│   Port: 8001         │      │   CDN-distributed    │
└──────────┬───────────┘      └──────────────────────┘
           │
           │ HTTPS
           │
┌──────────┴───────────┐
│   Sentinel HYDRA     │
│   (Edge Device)      │
│   ESP32-S3 WiFi      │
└──────────────────────┘
```

---

## Directory Structure

```
CARVanta/
├── api/                        # 28 FastAPI routers (v5)
├── scoring/                    # CVS v3 scoring engine
├── models/                     # ML pipeline (RF + XGBoost)
├── features/                   # Feature engineering + LLM + FHIR
├── validation/                 # Model validation + ISO certification
├── deep_learning/              # Autoencoder, attention, neural models
├── genomics/                   # Variant calling, HLA, TMB, neoantigen
├── digital_twin/               # Patient simulation engine
├── discovery/                  # Drug discovery, scFv design
├── copilot/                    # Research assistant, RAG engine
├── trials/                     # Clinical trial intelligence
├── collab/                     # Research collaboration hub
├── disease_atlas/              # Global disease epidemiology
├── health_econ/                # Cost-effectiveness analysis
├── omics/                      # Multi-omics integration
├── biomarker/                  # Biomarker data processing
├── safety/                     # Safety monitoring
├── regulatory/                 # Regulatory compliance documents
├── frontend-react/             # React 18 + Vite + TypeScript (45 pages)
├── data/                       # Biomarker database + reports
├── db/                         # Database models + migrations
├── config/                     # Application configuration
├── scripts/                    # Utility scripts
├── hardware/
│   └── sentinel/
│       ├── kicad/
│       │   └── Sentinel_HYDRA/         # KiCad project (6-layer PCB)
│       │       ├── *.kicad_sch         # 7 schematic sheets
│       │       ├── Sentinel_HYDRA.kicad_pcb
│       │       ├── gerbers/            # Production Gerber files
│       │       └── Sentinel_HYDRA_Gerbers.zip
│       ├── firmware/
│       │   ├── esp32_hydra/            # ESP32-S3 firmware (PlatformIO)
│       │   └── rp2040_hydra/           # RP2040 firmware (PlatformIO)
│       ├── BOM.md                      # Bill of materials
│       └── README.md                   # Hardware documentation
├── .github/
│   └── workflows/                      # CI/CD, CodeQL, release
├── ARCHITECTURE.md                     # This file
├── README.md                           # Project overview
├── CODE_OF_CONDUCT.md                  # Contributor Covenant v2.1
├── contributing.md                     # Contribution guidelines
├── security.md                         # Security policy
├── CHANGELOG.md                        # Version history
├── ROADMAP.md                          # Future plans
├── LICENSE                             # BUSL-1.1
└── requirements.txt                    # Python dependencies
```

---

## Security Architecture

### Authentication Flow

```
Client                    API                    Database
  │                        │                        │
  ├── POST /auth/register ─►│                        │
  │   (email, password)    │── PBKDF2 hash ────────►│
  │                        │                        │
  ├── POST /auth/login ───►│                        │
  │   (email, password)    │── Verify hash ◄────────│
  │◄── JWT token ──────────│                        │
  │                        │                        │
  ├── GET /api/v5/score ──►│                        │
  │   (Authorization: JWT) │── Verify + decode ─────│
  │◄── Response ───────────│                        │
```

### Defense Layers

| Layer | Mechanism |
|---|---|
| Transport | HTTPS / TLS 1.2+ (all endpoints) |
| Authentication | JWT with configurable expiry |
| Password Storage | PBKDF2 with per-user salt |
| API Protection | Rate limiting + CORS whitelist |
| Input Validation | Pydantic models for all endpoints |
| SQL Injection | Parameterized queries (SQLAlchemy) |
| Audit Trail | SQLite-backed request logging |
| LLM Safety | Output labeling (LLM vs. Rule-Based) |
| Firmware | TLS for cloud uploads, CRC for UART |

---

*Last updated: June 2026*

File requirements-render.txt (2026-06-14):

# ─── CARVanta API — Railway / Cloud Deployment ──────────────────────────────
# Optimized for Railway free/hobby tier (~512MB RAM)

# Core API
fastapi>=0.104.0
uvicorn[standard]>=0.24.0
pydantic>=2.5.0
python-multipart>=0.0.6

# Data & ML
pandas>=2.1.0
numpy>=1.24.0
scikit-learn>=1.3.0
xgboost>=2.0.0
joblib>=1.3.0
scipy>=1.11.0

# Config & Security
python-dotenv>=1.0.0

# HTTP (for LLM API calls)
httpx>=0.25.0
requests>=2.31.0

# Database
sqlalchemy>=2.0.0

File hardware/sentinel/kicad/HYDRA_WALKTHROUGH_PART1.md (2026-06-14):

# Sentinel Mark II "HYDRA" — KiCad 10 Walkthrough (Part 1: Schematic)

## Phase 1: Create Project
1. File → New Project → Name: `Sentinel_HYDRA` → Location: same kicad folder
2. Open .kicad_sch → File → Page Settings → Size: A3, Title: Sentinel HYDRA v1.0

## Phase 2: Create 7 Hierarchical Sheets
Right-click canvas → Add Hierarchical Sheet. Create:
- `Power.kicad_sch`
- `ESP32.kicad_sch`
- `RP2040.kicad_sch`
- `Electrochemical.kicad_sch`
- `Optical.kicad_sch`
- `Thermal.kicad_sch`
- `Sensors_Display.kicad_sch`

For each sheet: double-click to enter → add hierarchical pins for cross-sheet signals using Ctrl+H.

---

## Sheet 1: POWER

### Components to Place (press A to add)

| Ref | Symbol | Value |
|-----|---|---|
| J1 | Connector:USB_C_Receptacle_USB2.0 | USB-C |
| U13 | (Generic IC 24-pin) | BQ25895 |
| U14 | (Generic IC 14-pin) | TPS63020 |
| U15 | Regulator_Linear:TPS7A20 | 3V3_ANALOG |
| U16 | Regulator_Linear:AMS1117-3.3 | 3V3_DIGITAL |
| U17 | (Generic IC 8-pin) | MAX17048 |
| J12 | Connector:Conn_01x02_Pin | Battery |
| L1 | Device:Inductor | 4.7µH |
| L2 | Device:Ferrite_Bead | 600Ω |
| FB1 | Device:Ferrite_Bead | 600Ω |

### USB-C (J1) Wiring
| J1 Pin | Connect To |
|---|---|
| VBUS | BQ25895 VBUS (pin 1) |
| CC1 | 5.1kΩ → GND |
| CC2 | 5.1kΩ → GND |
| D+ | ESP32 GPIO20 (global label: USB_DP) |
| D- | ESP32 GPIO19 (global label: USB_DM) |
| GND | GND |
| SHIELD | GND |

### BQ25895 (U13) Wiring
| BQ25895 Pin | Connect To |
|---|---|
| VBUS | J1 VBUS via 10µF cap |
| PMID | 1µF to GND |
| SYS | TPS63020 VIN |
| BAT | J12 pin 1 (Battery+), 10µF to GND |
| REGN | 1µF to GND |
| BTST | 100nF to SW |
| SW | 2.2µH inductor → SYS |
| PGND | GND |
| SDA | Global label: I2C_SDA |
| SCL | Global label: I2C_SCL |
| CE | 10kΩ pulldown to GND |
| INT | Global label: CHG_INT |
| OTG | 10kΩ pulldown to GND |
| QON | 10kΩ pullup to SYS |

### TPS63020 (U14) Buck-Boost
| Pin | Connect To |
|-----|---|
| VIN | BQ25895 SYS |
| VOUT | Power symbol: **+3V3** (this IS the VSYS_3V3 / main 3.3V rail) |
| EN | VIN (always on) |
| PS/SYNC | GND (PWM mode) |
| PG | Global label: PG_3V3 |
| L1, L2 | 4.7µH inductor between them |
| GND | GND |
| VOUT caps | 22µF + 100nF to GND |
| VIN caps | 10µF + 100nF to GND |

### Analog LDO — TPS7A20 (U15)
| Pin | Connect To |
|-----|---|
| IN | **+3V3** power symbol via ferrite bead FB1 |
| OUT | Net label (Ctrl+L): `3V3_A` |
| EN | **+3V3** power symbol |
| GND | GND |
| Caps | 1µF in, 1µF out |

### Digital LDO — AMS1117-3.3 (U16)
| Pin | Connect To |
|-----|---|
| VI (IN) | **+3V3** power symbol + 10µF cap to GND |
| VO (OUT) | Net label (Ctrl+L): `3V3_D` + 22µF cap to GND |
| GND | GND power symbol |

> **Note**: `3V3_A` and `3V3_D` are **net labels** (Ctrl+L), NOT power symbols. They are used on downstream sheets to route the filtered rails.

### Fuel Gauge — MAX17048 (U17)
| Pin | Connect To |
|-----|---|
| VDD | **+3V3** power symbol, 100nF to GND |
| CELL | Global label (Ctrl+H): `VBAT` (battery voltage from J12 pin 1) |
| SDA | Global label: `I2C_SDA` |
| SCL | Global label: `I2C_SCL` |
| ALT | Global label: `BATT_ALT` |
| QSTRT | 10kΩ pullup to **+3V3** |
| GND | GND |

### Power Symbols & Flags (press P to open Power library)

| Symbol to Place | Search in Power lib | Purpose |
|---|---|---|
| `+3V3` | `+3V3` | Main 3.3V rail (TPS63020 VOUT) — place on every `+3V3` node |
| `GND` | `GND` | Ground — place on every GND pin |
| `VBAT` | `+VBAT` or type `VBAT` | Battery positive rail — J12 Pin 1 + BQ25895 BAT |
| `PWR_FLAG` | `PWR_FLAG` | **Required on: VBUS net, +3V3 net, VBAT net** to fix ERC errors |

> **VSYS_3V3 does NOT exist in KiCad's library.** Use the `+3V3` power symbol everywhere the walkthrough previously said VSYS_3V3.

> **PWR_FLAG placement**: Place one `PWR_FLAG` on: (1) the VBUS wire near J1, (2) the +3V3 wire near TPS63020 VOUT, (3) the VBAT wire near J12 pin 1. This tells KiCad these nets have a power source and clears ERC "power pin not driven" errors.

#### Battery Connector J12
| J12 Pin | Connect To |
|---|---|
| Pin 1 (BAT+) | Global label `VBAT` + 10µF cap to GND + PWR_FLAG |
| Pin 2 (BAT−) | GND power symbol |

#### L2 — DELETE
L2 (600Ω ferrite bead) is a duplicate of FB1. Select it → press Delete.

---

## Sheet 2: ESP32

### Components
| Ref | Symbol | Value |
|-----|---|---|
| U1 | RF_Module:ESP32-S3-WROOM-1 | ESP32-S3 |
| SW1 | Switch:SW_Push | RESET |
| SW2 | Switch:SW_Push | BOOT |
| C1-C4 | Device:C | 100nF, 100nF, 100nF, 22µF |
| R1-R4 | Device:R | 10kΩ each |

### ESP32 Pin Map

> **`3V3_D` is NOT a power symbol.** Use **Global label (Ctrl+H): `3V3_D`** on the ESP32 3V3 pin. This connects cross-sheet to AMS1117 (U16) VO on the Power sheet.

| ESP32 Pin | Net Label (Ctrl+L) or Global (Ctrl+H) | Purpose |
|---|---|---|
| 3V3 | Global label (Ctrl+H): `3V3_D` | Power from AMS1117 |
| GND | GND power symbol | Ground |
| EN | 10kΩ pullup to **global label `3V3_D`** + SW1 to GND + 100nF to GND | Reset |
| GPIO0 | 10kΩ pullup to **global label `3V3_D`** + SW2 to GND | Boot |
| GPIO1 | Global: UART_TX_ESP | → RP2040 RX |
| GPIO2 | Global: UART_RX_ESP | ← RP2040 TX |
| GPIO3 | Global: LED_DATA | WS2812B chain |
| GPIO4 | Global: BUZZER | Buzzer MOSFET |
| GPIO5 | Global: I2C_SDA | Main I2C bus |
| GPIO6 | Global: I2C_SCL | Main I2C bus |
| GPIO7 | Global: TFT_DC | Display |
| GPIO8 | Global: TFT_CS | Display |
| GPIO9 | Global: TFT_RST | Display |
| GPIO10 | Global: TFT_BL | Backlight |
| GPIO11 | Global: SPI0_MOSI | TFT + SD |
| GPIO12 | Global: SPI0_SCK | TFT + SD |
| GPIO13 | Global: SPI0_MISO | TFT + SD |
| GPIO14 | Global: SD_CS | SD card |
| GPIO15 | Global: CHG_INT | From BQ25895 |
| GPIO16 | Global: BATT_ALT | From MAX17048 |
| GPIO17 | Global: PG_3V3 | Power good |
| GPIO19 | Global: USB_DM | USB D− (hardware fixed, cannot remap) |
| GPIO20 | Global: USB_DP | USB D+ (hardware fixed, cannot remap) |

### Bypass Caps
Place 3× 100nF + 1× 22µF between 3V3 and GND, right next to ESP32.

---

## Sheet 3: RP2040

### Components
| Ref | Symbol | Value |
|-----|---|---|
| U2 | MCU_RaspberryPi:RP2040 | RP2040 |
| U3 | Memory_Flash:W25Q16JV | 2MB Flash |
| Y1 | Device:Crystal | 12MHz |
| C5-C12 | Device:C | various |
| R5-R8 | Device:R | various |

### RP2040 Pin Map

> **`3V3_D` = Global label (Ctrl+H)** everywhere below — NOT a power symbol.
> **IOVDD** in the KiCad symbol is ONE pin representing all 4 physical IOVDD pads — connect it once.

| RP2040 Pin | Connect To | How |
|---|---|-----|
| IOVDD | Global label `3V3_D` + 100nF to GND | Ctrl+H |
| VREG_VIN | Global label `3V3_D` + 100nF to GND | Ctrl+H |
| VREG_VOUT | Wire directly to DVDD pin + 1µF to GND | Wire |
| DVDD | Connected to VREG_VOUT + 1µF to GND | Wire |
| USB_VDD | Global label `3V3_D` + 100nF to GND | Ctrl+H |
| ADC_AVDD | Global label `3V3_D` + 100nF to GND | Ctrl+H |
| GND | GND power symbol | P |
| XIN | 12MHz crystal pin 1, 15pF to GND | Wire |
| XOUT | 12MHz crystal pin 2, 15pF to GND | Wire |
| RUN | 10kΩ pullup to global label `3V3_D` | Ctrl+H |
| GPIO0 | Global: `UART_RX_RP` | Ctrl+H |
| GPIO1 | Global: `UART_TX_RP` | Ctrl+H |
| GPIO2 | Global: `AD5941_1_CS` | Ctrl+H |
| GPIO3 | Global: `AD5941_1_RST` | Ctrl+H |
| GPIO4 | Global: `AD5941_2_CS` | Ctrl+H |
| GPIO5 | Global: `AD5941_2_RST` | Ctrl+H |
| GPIO6 | Global: `SPI1_SCK` | Ctrl+H |
| GPIO7 | Global: `SPI1_MOSI` | Ctrl+H |
| GPIO8 | Global: `SPI1_MISO` | Ctrl+H |
| GPIO9 | Global: `AD5941_1_INT` | Ctrl+H |
| GPIO10 | Global: `AD5941_2_INT` | Ctrl+H |
| GPIO11 | Global: `I2C1_SDA` | Ctrl+H |
| GPIO12 | Global: `I2C1_SCL` | Ctrl+H |
| GPIO13 | Global: `HEATER_PWM` | Ctrl+H |
| GPIO14 | Global: `UV_LED_EN` | Ctrl+H |
| GPIO15 | Global: `BLUE_LED_EN` | Ctrl+H |
| GPIO16 | Global: `WHITE_LED_EN` | Ctrl+H |
| QSPI_SS | Wire to W25Q16 CS (pin 1) | Wire |
| QSPI_SCLK | Wire to W25Q16 CLK (pin 6) | Wire |
| QSPI_SD0 | Wire to W25Q16 DI (pin 5) | Wire |
| QSPI_SD1 | Wire to W25Q16 DO (pin 2) | Wire |
| QSPI_SD2 | Wire to W25Q16 WP (pin 3) + 10kΩ pullup to `3V3_D` | Wire |
| QSPI_SD3 | Wire to W25Q16 HOLD (pin 7) + 10kΩ pullup to `3V3_D` | Wire |
| SWDIO | Wire to J13 pin 2 (SWD debug connector) | Wire |
| SWCLK | Wire to J13 pin 4 (SWD debug connector) | Wire |

### UART Cross-Connect (CRITICAL)
```
ESP32 GPIO1 (TX) ──────→ RP2040 GPIO0 (RX)
ESP32 GPIO2 (RX) ←────── RP2040 GPIO1 (TX)
```

### W25Q16JV Flash (U3)
| Pin | Connect To |
|-----|---|
| 1 (CS) | RP2040 QSPI_SS |
| 2 (DO) | RP2040 QSPI_SD1 |
| 3 (WP) | 10kΩ to 3V3_D |
| 4 (GND) | GND |
| 5 (DI) | RP2040 QSPI_SD0 |
| 6 (CLK) | RP2040 QSPI_SCLK |
| 7 (HOLD) | 10kΩ to 3V3_D |
| 8 (VCC) | 3V3_D, 100nF to GND |

---

## Sheet 4: ELECTROCHEMICAL (2× AD5941)

### Components
| Ref | Symbol | Value |
|-----|---|---|
| U4 | (Generic IC 48-pin or custom) | AD5941 #1 |
| U5 | (Generic IC 48-pin or custom) | AD5941 #2 |
| J2-J9 | Connector:Conn_01x03_Pin | 8× sensor connectors |
| C13-C28 | Device:C | Bypass caps |
| R9-R12 | Device:R | RCAL 10kΩ |

### AD5941 #1 (U4) — Channels 1–4
| Pin | Connect To |
|-----|---|
| AVDD1 | 3V3_A, 100nF + 10µF to GND |
| AVDD2 | 3V3_A, 100nF to GND |
| DVDD | 3V3_D, 100nF to GND |
| IOVDD | 3V3_D, 100nF to GND |
| AGND | GND |
| DGND | GND |
| VREF_2V5 | 1µF to GND (internal ref bypass) |
| VREF_1V82 | 1µF to GND (internal ref bypass) |
| VBIAS_CAP | 1µF to GND |
| DVDD_REG_1V8 | 1µF to GND (internal regulator) |
| SCK | Global: SPI1_SCK |
| MOSI | Global: SPI1_MOSI |
| MISO | Global: SPI1_MISO |
| CS | Global: AD5941_1_CS |
| RESET | Global: AD5941_1_RST |
| INT0 | Global: AD5941_1_INT |
| AIN0 | J2 pin 1 (WE Ch1) |
| AIN1 | J3 pin 1 (WE Ch2) |
| AIN2 | J4 pin 1 (WE Ch3) |
| AIN3 | J5 pin 1 (WE Ch4) |
| CE0 | Sensor CE bus (Counter Electrode) |
| RE0 | Sensor RE bus (Reference Electrode) |
| SE0 | RTIA feedback |
| DE0 | Excitation out |
| RCAL0 | 10kΩ precision resistor |
| RCAL1 | Other end of 10kΩ |
| EP (exposed pad) | GND |

### AD5941 #2 (U5) — same wiring, different CS/RST/INT
- CS → AD5941_2_CS, RST → AD5941_2_RST, INT → AD5941_2_INT
- AIN0-3 → J6-J9 pin 1

### Sensor Connectors (J2–J9)
Each 3-pin connector:
| Pin | Signal |
|-----|---|
| 1 | WE (Working Electrode) → AD5941 AINx |
| 2 | RE (Reference Electrode) → AD5941 RE0 |
| 3 | CE (Counter Electrode) → AD5941 CE0 |

---

## Sheet 5: OPTICAL

### Components
| Ref | Symbol | Value |
|-----|---|---|
| U6 | (Generic IC 8-pin) | AS7341 |
| LED1 | Device:LED | UV 365nm |
| LED2 | Device:LED | Blue 470nm |
| LED3 | Device:LED | White |
| R13-R15 | Device:R | Current limiting |
| Q3-Q5 | Transistor_FET:2N7002 | LED drivers |

### AS7341 (U6)
| Pin | Connect To |
|-----|---|
| VDD | 3V3_A, 100nF to GND |
| GND | GND |
| SDA | Global: I2C1_SDA |
| SCL | Global: I2C1_SCL |
| INT | Global: SPEC_INT (to RP2040 GPIO17 if available) |
| LDR | GPIO_LDR (optional) |
| NC pins | Leave unconnected |

### LED Drivers (each LED)
```
RP2040 GPIOx → 100Ω → 2N7002 Gate
                       2N7002 Source → GND
                       2N7002 Drain → LED cathode
                       LED anode → 3V3_D via current-limit R
```
| LED | Gate GPIO | Series R (anode) |
|-----|---|---|
| UV 365nm | GPIO14 (UV_LED_EN) | 68Ω (20mA) |
| Blue 470nm | GPIO15 (BLUE_LED_EN) | 47Ω (20mA) |
| White | GPIO16 (WHITE_LED_EN) | 100Ω (15mA) |

---

## Sheet 6: THERMAL

### Components
| Ref | Symbol | Value |
|-----|---|---|
| U12 | (Generic IC 6-pin) | TMP117 |
| Q2 | Transistor_FET:AO3400 | Heater MOSFET |
| R16 | Device:R | 100Ω gate |
| R17 | Device:R | 10kΩ gate pulldown |

### TMP117 (U12)
| Pin | Connect To |
|-----|---|
| V+ | 3V3_A, 100nF to GND |
| GND | GND |
| SDA | Global: I2C1_SDA |
| SCL | Global: I2C1_SCL |
| ALERT | Global: TEMP_ALERT |
| ADD0 | GND (address 0x48) |

### Heater Driver
```
RP2040 GPIO13 (HEATER_PWM) → 100Ω → AO3400 Gate
                                     AO3400 Source → GND  
                                     AO3400 Drain → HTR1 pad
                                     HTR1 other pad → VSYS_3V3
10kΩ from Gate to GND (pulldown, heater OFF by default)
```

---

## Sheet 7: SENSORS & DISPLAY

### Components
| Ref | Symbol |
|-----|---|
| U7 | Interface_I2C:TCA9548A |
| U8 | (Generic) MAX30102 |
| U9 | (Generic) MLX90614 |
| U10 | Timer:DS3231M |
| U11 | (Generic) LSM6DSO |
| J10 | Connector:Conn_01x14_Pin (TFT) |
| J11 | Connector:Conn_01x07_Pin (SD) |
| D1-D4 | LED:WS2812B |
| BZ1 | Device:Buzzer |
| Q1 | Transistor_FET:2N7002 |

### TCA9548A (U7) — I2C Mux
| Pin | Connect To |
|-----|---|
| SDA | Global: I2C_SDA |
| SCL | Global: I2C_SCL |
| VCC | 3V3_D, 100nF to GND |
| GND | GND |
| A0,A1,A2 | GND (address 0x70) |
| RESET | 3V3_D (always active) |
| SD0/SC0 | MAX30102 SDA/SCL |
| SD1/SC1 | MLX90614 SDA/SCL |
| SD2/SC2 | DS3231 SDA/SCL |
| SD3/SC3 | LSM6DSO SDA/SCL |
| SD4-SD7 | NC (spare) |

### Sensor Wiring (each gets 100nF bypass)
| Sensor | VDD | GND | I2C Channel |
|---|-----|-----|---|
| MAX30102 | 3V3_D | GND | Ch0 |
| MLX90614 | 3V3_D | GND | Ch1 |
| DS3231 | 3V3_D | GND | Ch2 |
| LSM6DSO | 3V3_D | GND | Ch3 |

### TFT Display (J10) — 14-pin FPC
| Pin | Signal |
|-----|---|
| 1 | GND |
| 2 | 3V3_D |
| 3 | TFT_CS |
| 4 | TFT_DC |
| 5 | TFT_RST |
| 6 | SPI0_MOSI |
| 7 | SPI0_SCK |
| 8 | TFT_BL |
| 9-14 | GND |

### microSD (J11) — SPI mode
| Pin | Signal |
|-----|---|
| 1 | SD_CS |
| 2 | SPI0_MOSI |
| 3 | GND |
| 4 | 3V3_D |
| 5 | SPI0_SCK |
| 6 | GND |
| 7 | SPI0_MISO |

### WS2812B Chain (D1→D2→D3→D4)
- D1 DIN ← Global: LED_DATA
- D1 DOUT → D2 DIN → D3 DIN → D4 DIN
- Each: VDD → 3V3_D, GND → GND, 100nF bypass per LED

### Buzzer
- GPIO4 → 100Ω → Q1 Gate
- Q1 Drain → BZ1 negative
- BZ1 positive → 3V3_D
- Q1 Source → GND

---

## ERC Checklist
1. Add PWR_FLAG on VBUS, BAT+, and any power net that has no driver
2. Add no-connect flags (Q) on unused pins
3. Run Inspect → ERC → fix ALL errors → target: 0

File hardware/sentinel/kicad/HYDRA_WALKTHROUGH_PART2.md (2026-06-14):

# Sentinel Mark II "HYDRA" — KiCad 10 Walkthrough (Part 2: Footprints → PCB → Order)

## Phase 3: Assign Footprints

Tools → Assign Footprints. Use this table:

### ICs & Modules
| Component | KiCad Footprint |
|---|---|
| ESP32-S3-WROOM-1 | RF_Module:ESP32-S3-WROOM-1 |
| RP2040 | Package_DFN_QFN:QFN-56-1EP_7x7mm_P0.4mm_EP3.2x3.2mm |
| W25Q16JV | Package_SO:SOIC-8_3.9x4.9mm_P1.27mm |
| AD5941 (×2) | Package_CSP:LFCSP-48-1EP_7x7mm_P0.5mm_EP5.6x5.6mm |
| AS7341 | Custom or OLGA-8 (3.1×2mm) — download from SnapEDA |
| TCA9548A | Package_SO:TSSOP-24_4.4x7.8mm_P0.65mm |
| MAX30102 | Package_DFN_QFN:OLGA-14_3.3x5.6mm_P0.8mm |
| MLX90614 | Package_TO_SOT_THT:TO-39-4_Window |
| DS3231 | Package_SO:SOIC-8_3.9x4.9mm_P1.27mm |
| LSM6DSO | Package_DFN_QFN:LGA-14_3x2.5mm_P0.5mm |
| TMP117 | Package_DFN_QFN:DSBGA-6_1.5x1.0mm |
| BQ25895 | Package_DFN_QFN:VQFN-24-1EP_4x4mm_P0.5mm |
| TPS63020 | Package_DFN_QFN:QFN-14-1EP_3.5x4.5mm_P0.65mm |
| TPS7A20 | Package_TO_SOT_SMD:SOT-23-5 |
| AMS1117 | Package_TO_SOT_SMD:SOT-223-3_TabPin2 |
| MAX17048 | Package_DFN_QFN:DFN-8-1EP_2x2mm_P0.5mm |

### Connectors
| Component | KiCad Footprint |
|---|---|
| USB-C (J1) | Connector_USB:USB_C_Receptacle_HRO_TYPE-C-31-M-12 |
| Sensor 3-pin (J2-J9) | Connector_Molex:Molex_PicoBlade_53047-0310 |
| TFT FPC (J10) | Connector_FFC-FPC:Hirose_FH12-14S-0.5SH |
| microSD (J11) | Connector_Card:microSD_HC_Molex_104031-0811 |
| Battery (J12) | Connector_JST:JST_PH_B2B-PH-K_1x02_P2.00mm_Vertical |
| SWD Debug (J13) | Connector:Tag-Connect_TC2050-IDC |

### Passives
| Component | KiCad Footprint |
|---|---|
| All 0402 caps (≤1µF) | Capacitor_SMD:C_0402_1005Metric |
| 0805 caps (10µF, 22µF) | Capacitor_SMD:C_0805_2012Metric |
| All 0402 resistors | Resistor_SMD:R_0402_1005Metric |
| 4.7µH inductor | Inductor_SMD:L_Taiyo-Yuden_NR-40xx |
| Ferrite bead | Inductor_SMD:L_0402_1005Metric |
| 12MHz crystal | Crystal:Crystal_SMD_3215-2Pin_3.2x1.5mm |

### Actuation
| Component | KiCad Footprint |
|---|---|
| WS2812B (D1-D4) | LED_SMD:LED_WS2812B_PLCC4_5.0x5.0mm_P3.2mm |
| UV/Blue/White LED | LED_SMD:LED_0805_2012Metric |
| Buzzer | Buzzer_Beeper:Buzzer_12x9.5RM7.6 |
| 2N7002 MOSFET | Package_TO_SOT_SMD:SOT-23 |
| AO3400 MOSFET | Package_TO_SOT_SMD:SOT-23 |
| Tactile switch | Button_Switch_SMD:SW_SPST_TL3342 |

Click Apply → OK.

---

## Phase 4: PCB Layout

### Step 4.1 — Import to PCB
1. Open PCB Editor
2. Tools → Update PCB from Schematic (F8)
3. Click Update PCB → Close
4. All components appear in a cluster

### Step 4.2 — Board Setup
1. File → Board Setup → Board Stackup → Physical Stackup
2. Set Copper Layers: **6**
3. Rename layers:
   - F.Cu → Digital_Signals
   - In1.Cu → GND_Plane
   - In2.Cu → Analog_Signals
   - In3.Cu → Power_Planes
   - In4.Cu → HighSpeed
   - B.Cu → Bottom_GND
4. Thickness: 1.6mm total (default is fine)
5. Click OK

### Step 4.3 — Design Rules
Board Setup → Design Rules → Net Classes:

| Name | Clearance | Track Width | Via Size | Via Hole |
|---|---|---|---|---|
| Default | 0.15 | 0.2 | 0.3 | 0.3 |
| Power | 0.2 | 0.5 | 0.6 | 0.4 |
| Analog | 0.2 | 0.25 | 0.5 | 0.3 |
| USB_DP | 0.15 | 0.18 | 0.3 | 0.3 |
| HighCurrent | 0.25 | 0.8 | 0.6 | 0.5 |

Netclass Assignments:
| Pattern | Net Class |
|---|---|
| 3V3* | Power |
| GND | Power |
| VBAT | Power |
| VSYS* | Power |
| USB_D* | USB_DP |
| *VOUT* | Analog |
| SPI1* | Analog |

### Step 4.4 — Board Outline
1. Select layer: Edge.Cuts
2. Place → Line → draw 100mm × 100mm rectangle
3. Start at (0,0), corners at (100,0), (100,100), (0,100)

### Step 4.5 — Component Placement

Place components using: Click component → Press E → type X, Y.

#### MCU Zone (top half)
| Ref | X | Y | Notes |
|-----|---|---|---|
| U1 (ESP32) | 25 | 15 | Antenna at top edge |
| U2 (RP2040) | 65 | 20 | Center-right |
| U3 (Flash) | 75 | 20 | Next to RP2040 |
| Y1 (Crystal) | 60 | 18 | Near RP2040 XIN/XOUT |
| SW1 | 12 | 28 | Reset button |
| SW2 | 12 | 33 | Boot button |
| J13 (SWD) | 80 | 15 | Debug header |

#### Power Zone (left side)
| Ref | X | Y | Notes |
|-----|---|---|---|
| J1 (USB-C) | 5 | 45 | Left edge |
| U13 (BQ25895) | 18 | 40 | Near USB |
| L1 (inductor) | 22 | 35 | Buck-boost inductor |
| U14 (TPS63020) | 30 | 40 | Buck-boost |
| U15 (TPS7A20) | 30 | 50 | Analog LDO |
| U16 (AMS1117) | 18 | 50 | Digital LDO |
| U17 (MAX17048) | 12 | 55 | Fuel gauge |
| J12 (Battery) | 5 | 55 | Battery connector |
| FB1 | 28 | 50 | Analog ferrite |

#### Electrochemical Zone (bottom-center)
| Ref | X | Y | Notes |
|-----|---|---|---|
| U4 (AD5941 #1) | 35 | 65 | Channels 1-4 |
| U5 (AD5941 #2) | 60 | 65 | Channels 5-8 |
| J2-J5 | 25,35,45,55 | 90 | Sensor ports 1-4 |
| J6-J9 | 55,65,75,85 | 90 | Sensor ports 5-8 |

#### Optical Zone (right side)
| Ref | X | Y | Notes |
|-----|---|---|---|
| U6 (AS7341) | 85 | 45 | Spectral sensor |
| LED1 (UV) | 82 | 40 | UV excitation |
| LED2 (Blue) | 85 | 40 | Blue excitation |
| LED3 (White) | 88 | 40 | White reference |
| Q3-Q5 | 82,85,88 | 38 | LED MOSFETs |

#### Thermal Zone (bottom-right)
| Ref | X | Y | Notes |
|-----|---|---|---|
| U12 (TMP117) | 85 | 80 | Precision temp |
| Q2 (Heater FET) | 80 | 78 | Heater driver |
| HTR1 zone | 75-95 | 82-98 | Copper meander area |

#### Sensor Array (right side)
| Ref | X | Y | Notes |
|-----|---|---|---|
| U7 (TCA9548A) | 55 | 45 | I2C mux |
| U8 (MAX30102) | 65 | 35 | SpO2 |
| U9 (MLX90614) | 75 | 35 | IR temp |
| U10 (DS3231) | 65 | 45 | RTC |
| U11 (LSM6DSO) | 75 | 45 | IMU |

#### Display Zone (top-right)
| Ref | X | Y | Notes |
|-----|---|---|---|
| J10 (TFT FPC) | 95 | 20 | Right edge |
| D1-D4 (WS2812B) | 50,57,64,71 | 8 | LED strip |
| BZ1 (Buzzer) | 45 | 5 | Top area |
| Q1 (Buzzer FET) | 43 | 8 | Near buzzer |
| J11 (microSD) | 90 | 55 | Right side |

### Step 4.6 — Copper Zones (Ground & Power Planes)

**Zone 1 — GND Plane:**
1. Select In1.Cu → Place → Draw Filled Zone
2. Net: GND, Clearance: 0.3mm → OK
3. Draw rectangle over entire board → press B

**Zone 2 — Power Plane:**
1. Select In3.Cu → Place → Draw Filled Zone
2. Net: VSYS_3V3, Clearance: 0.3mm → OK
3. Draw rectangle over entire board → press B

**Zone 3 — Bottom GND:**
1. Select B.Cu → Place → Draw Filled Zone
2. Net: GND, Clearance: 0.3mm → OK
3. Draw rectangle over entire board → press B

Press **B** to fill all zones.

### Step 4.7 — Heater Trace (Thermal Zone)
1. Select B.Cu layer
2. Place → Line (graphic line) on B.Cu in a serpentine/meander pattern
3. Area: 20mm × 15mm at bottom-right
4. Trace width: 1mm, spacing: 0.5mm
5. Connect both ends to pads of Q2 drain and VSYS

---

## Phase 5: Routing

### Option A — Freerouting (Auto)
1. Tools → Freerouting → Export DSN
2. If Freerouting crashes, remove copper zones first (Edit → Select All on In1.Cu → Delete), export DSN, then re-add zones after import
3. Launch standalone: `& "C:\Program Files\Eclipse Adoptium\jre-25.0.3.9-hotspot\bin\java.EXE" -jar "c:\Users\dhruv\CARVanta\hardware\sentinel\kicad\freerouting.jar"`
4. File → Open → select .dsn file
5. Click Autorouter → wait
6. File → Save As → .ses file
7. Back in KiCad: File → Import → Specctra Session

### Option B — Manual Routing
Press X to route. Priority order:
1. **Analog traces** (In2.Cu): AD5941 ↔ sensor connectors — keep short
2. **SPI buses**: RP2040 ↔ AD5941 (SPI1), ESP32 ↔ TFT/SD (SPI0)
3. **I2C buses**: ESP32 ↔ TCA9548A, RP2040 ↔ AS7341/TMP117
4. **UART**: ESP32 ↔ RP2040 cross-connect
5. **Power**: Wide traces (0.5mm+) for VBUS, VSYS, battery
6. **USB**: Differential pair on In4.Cu

Press V while routing to add a via (switch layer).

---

## Phase 6: DRC
1. Inspect → Design Rules Checker
2. Run DRC
3. Fix all errors → target: 0 errors, 0 warnings
4. Common fixes: clearance → move trace, unconnected → route it

---

## Phase 7: Manufacturing Files

### Gerbers
1. File → Fabrication Outputs → Gerbers
2. Select layers: F.Cu, In1.Cu, In2.Cu, In3.Cu, In4.Cu, B.Cu, F.SilkS, B.SilkS, F.Mask, B.Mask, Edge.Cuts
3. Output: `\gerber\` folder
4. Click Plot

### Drill Files
1. File → Fabrication Outputs → Drill Files
2. Format: Excellon, Units: mm
3. Click Generate

### BOM + CPL
1. File → Fabrication Outputs → Component Placement
2. Generates pick-and-place CSV

---

## Phase 8: Order from JLCPCB

1. Go to jlcpcb.com → Order Now
2. Upload Gerber ZIP
3. Settings:
   - Layers: **6**
   - Thickness: **1.6mm**
   - Surface Finish: **ENIG** (gold pads)
   - Solder Mask: **Black**
   - Silkscreen: **White**
   - Via Covering: **Tented**
   - Impedance Control: **Yes** (90Ω USB)
4. Enable SMT Assembly → upload BOM.csv + CPL.csv
5. Estimated cost: **$80-120 for 5 boards assembled**
6. Shipping: 5-7 days DHL

---

## Component Count Summary

| Category | Count |
|---|---|
| ICs/Modules | 17 |
| Connectors | 13 |
| Capacitors | ~45 |
| Resistors | ~20 |
| Inductors/Ferrites | 3 |
| LEDs (WS2812B) | 4 |
| LEDs (Excitation) | 3 |
| MOSFETs | 4 |
| Switches | 2 |
| Crystal | 1 |
| Buzzer | 1 |
| **TOTAL** | **~113** |

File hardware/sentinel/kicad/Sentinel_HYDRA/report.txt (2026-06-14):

Info: X scale constrained.
Info: Y scale constrained.
Plotted to 'C:\Users\dhruv\CARVanta\hardware\sentinel\kicad\Sentinel_HYDRA\Sentinel_HYDRA-Digital_Signals.gbr'.
Plotted to 'C:\Users\dhruv\CARVanta\hardware\sentinel\kicad\Sentinel_HYDRA\Sentinel_HYDRA-GND_Plane.gbr'.
Plotted to 'C:\Users\dhruv\CARVanta\hardware\sentinel\kicad\Sentinel_HYDRA\Sentinel_HYDRA-Analog_Signals.gbr'.
Plotted to 'C:\Users\dhruv\CARVanta\hardware\sentinel\kicad\Sentinel_HYDRA\Sentinel_HYDRA-Power_Planes.gbr'.
Plotted to 'C:\Users\dhruv\CARVanta\hardware\sentinel\kicad\Sentinel_HYDRA\Sentinel_HYDRA-HighSpeed.gbr'.
Plotted to 'C:\Users\dhruv\CARVanta\hardware\sentinel\kicad\Sentinel_HYDRA\Sentinel_HYDRA-Bottom_GND.gbr'.
Plotted to 'C:\Users\dhruv\CARVanta\hardware\sentinel\kicad\Sentinel_HYDRA\Sentinel_HYDRA-F_Paste.gbr'.
Plotted to 'C:\Users\dhruv\CARVanta\hardware\sentinel\kicad\Sentinel_HYDRA\Sentinel_HYDRA-B_Paste.gbr'.
Plotted to 'C:\Users\dhruv\CARVanta\hardware\sentinel\kicad\Sentinel_HYDRA\Sentinel_HYDRA-F_Silkscreen.gbr'.
Plotted to 'C:\Users\dhruv\CARVanta\hardware\sentinel\kicad\Sentinel_HYDRA\Sentinel_HYDRA-B_Silkscreen.gbr'.
Plotted to 'C:\Users\dhruv\CARVanta\hardware\sentinel\kicad\Sentinel_HYDRA\Sentinel_HYDRA-F_Mask.gbr'.
Plotted to 'C:\Users\dhruv\CARVanta\hardware\sentinel\kicad\Sentinel_HYDRA\Sentinel_HYDRA-B_Mask.gbr'.
Plotted to 'C:\Users\dhruv\CARVanta\hardware\sentinel\kicad\Sentinel_HYDRA\Sentinel_HYDRA-Edge_Cuts.gbr'.
Created Gerber job file 'C:\Users\dhruv\CARVanta\hardware\sentinel\kicad\Sentinel_HYDRA\Sentinel_HYDRA-job.gbrjob'.
Plotted to 'C:\Users\dhruv\CARVanta\hardware\sentinel\kicad\Sentinel_HYDRA\Sentinel_HYDRA-Digital_Signals.gbr'.
Plotted to 'C:\Users\dhruv\CARVanta\hardware\sentinel\kicad\Sentinel_HYDRA\Sentinel_HYDRA-GND_Plane.gbr'.
Plotted to 'C:\Users\dhruv\CARVanta\hardware\sentinel\kicad\Sentinel_HYDRA\Sentinel_HYDRA-Analog_Signals.gbr'.
Plotted to 'C:\Users\dhruv\CARVanta\hardware\sentinel\kicad\Sentinel_HYDRA\Sentinel_HYDRA-Power_Planes.gbr'.
Plotted to 'C:\Users\dhruv\CARVanta\hardware\sentinel\kicad\Sentinel_HYDRA\Sentinel_HYDRA-HighSpeed.gbr'.
Plotted to 'C:\Users\dhruv\CARVanta\hardware\sentinel\kicad\Sentinel_HYDRA\Sentinel_HYDRA-Bottom_GND.gbr'.
Plotted to 'C:\Users\dhruv\CARVanta\hardware\sentinel\kicad\Sentinel_HYDRA\Sentinel_HYDRA-F_Paste.gbr'.
Plotted to 'C:\Users\dhruv\CARVanta\hardware\sentinel\kicad\Sentinel_HYDRA\Sentinel_HYDRA-B_Paste.gbr'.
Plotted to 'C:\Users\dhruv\CARVanta\hardware\sentinel\kicad\Sentinel_HYDRA\Sentinel_HYDRA-F_Silkscreen.gbr'.
Plotted to 'C:\Users\dhruv\CARVanta\hardware\sentinel\kicad\Sentinel_HYDRA\Sentinel_HYDRA-B_Silkscreen.gbr'.
Plotted to 'C:\Users\dhruv\CARVanta\hardware\sentinel\kicad\Sentinel_HYDRA\Sentinel_HYDRA-F_Mask.gbr'.
Plotted to 'C:\Users\dhruv\CARVanta\hardware\sentinel\kicad\Sentinel_HYDRA\Sentinel_HYDRA-B_Mask.gbr'.
Plotted to 'C:\Users\dhruv\CARVanta\hardware\sentinel\kicad\Sentinel_HYDRA\Sentinel_HYDRA-Edge_Cuts.gbr'.
Created Gerber job file 'C:\Users\dhruv\CARVanta\hardware\sentinel\kicad\Sentinel_HYDRA\Sentinel_HYDRA-job.gbrjob'.
Info: Done.
Info: Done.

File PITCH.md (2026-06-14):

# CARVanta — The AI That's Racing to Save Cancer Patients Before Time Runs Out

## The Moment That Changes Everything

A doctor sits across from a family and says five words: *"Your child has blood cancer."*

What follows is a race against time. The cancer is growing. The clock is ticking. And somewhere in the world, there's a treatment that could save this child's life — **CAR-T cell therapy** — where doctors reprogram the patient's own immune cells to hunt and destroy cancer.

But here's what nobody tells the family:

**Finding the right target for that therapy takes 5–10 years of research. And a single treatment costs $500,000.**

**CARVanta was built to change that.**

---

## What Is CAR-T Therapy?

Your immune system has T-cells — soldiers that patrol your body looking for invaders. Cancer is clever: it disguises itself so T-cells walk right past it.

CAR-T therapy is the hack. Doctors extract the patient's T-cells, genetically engineer them by adding a "GPS antenna" (a **C**himeric **A**ntigen **R**eceptor) that locks onto a specific marker on the cancer cell, multiply millions of these cells, and infuse them back. These supercharged T-cells now recognize and kill the cancer — a biological guided missile.

**But the entire therapy depends on picking the right target marker.** Pick the wrong one, and the missile misses. Or worse — it attacks healthy organs.

---

## What CARVanta Does

CARVanta is two connected systems solving one problem: **keeping cancer patients alive.**

### 🖥️ The Software: AI Target Discovery Platform

**117,000 lines of code. 45 pages. 214 Python modules. 30+ API endpoints.**

A cloud-deployed platform where a doctor or researcher:

1. **Types a cancer antigen name** — CARVanta instantly scores it across 8 scientific dimensions using real data from TCGA, GTEx, and the Human Protein Atlas
2. **Machine learning models** (Random Forest + XGBoost) trained on FDA-approved targets predict viability
3. **An LLM** writes a clinical reasoning summary explaining *why* in plain English
4. **A Digital Twin** simulates how *this specific patient* responds to *this specific target*
5. **A Trial Matcher** finds every qualifying clinical trial worldwide, ranked by proximity

What used to take researchers 3–5 years now takes **minutes**.

### 🔬 The Hardware: Sentinel HYDRA

**50 firmware files. 6-layer medical PCB. Dual-processor architecture.**

A credit-card-sized device at the patient's bedside that **continuously monitors** blood biomarkers through a disposable sensor strip:

- **4 antigen levels simultaneously** — catches cancer escaping the therapy
- **SpO2 + heart rate** — early cytokine storm warning
- **11 spectral channels** — optical biomarker analysis
- **Impedance spectroscopy** — cell health assessment
- **Results in 30 seconds → WiFi upload to CARVanta cloud → doctor alerted instantly**

---

## Why 117,000 Lines?

Because biology doesn't play by simple rules:

| What's Needed | Lines of Code | Why |
|---|---|-----|
| Genomic variant caller | ~49,000 lines | Parsing VCF/FASTA, detecting SNVs, indels, CNVs, gene fusions |
| Digital Twin engine | ~35,000 lines | PK/PD modeling, immune simulation, tumor dynamics, CRS prediction |
| 45 React UI pages | ~25,000 lines | From login to genomic profiler to 3D neural bridge |
| Clinical trials intelligence | ~15,000 lines | ClinicalTrials.gov sync, eligibility matching, DSMB reports |
| Embedded firmware (C++) | ~5,000 lines | Dual-MCU sensor control, electrochemistry, PID heater, WiFi |
| Drug discovery pipeline | ~12,000 lines | scFv design, molecular docking, ADMET, toxicity prediction |
| Everything else | ~25,000 lines | Auth, billing, NLP, LLM, collaboration, safety, compliance |

---

## How It All Connects

```
Patient blood (fingerprick)
        │
        ▼
┌───────────────────────┐
│   SENTINEL HYDRA      │     Bedside device
│   Measures 4 antigens │     95×65mm, ~$50/unit
│   + vitals + spectral │
└───────────┬───────────┘
            │ WiFi
            ▼
┌───────────────────────────────────────┐
│        CARVANTA CLOUD                  │
│                                        │
│  📊 Real-time biomarker trends         │
│  🤖 AI: "CD19 dropping — escape risk"  │
│  🧬 Genomic: "Switch to CD22 target"   │
│  🧑‍⚕️ Twin: "85% response if switched"   │
│  🏥 Trials: "3 CD22 trials nearby"     │
│  🔔 → Doctor's phone: "Act now"        │
└───────────────────────────────────────┘
```

---

## Why This Is a Gamechanger

**1. It closes the loop** — Software picks the target → hardware monitors the treatment → data improves the AI. A continuous learning cycle.

**2. It turns days into seconds** — Detecting antigen escape (the #1 reason CAR-T fails) currently takes days via lab tests. The Sentinel detects it in 30 seconds.

**3. It democratizes access** — A researcher in Mumbai uses the same AI as Harvard. The hardware costs ~$50, not $50,000.

**4. 4 antigens, not 1** — Cancer downregulates one antigen and escapes through another. HYDRA monitors 4 simultaneously, catching escape mutations before they kill.

---

## The Numbers

| Metric | Value |
|---|---|
| Lines of code | **117,000+** |
| Source files | **778** |
| Python AI modules | **214** |
| React UI pages | **45** |
| API endpoints | **30+** |
| Scored biomarkers | **500+** |
| Firmware files | **50** |
| PCB layers | **6** |
| Simultaneous antigen channels | **4** |
| Measurement cycle | **30 seconds** |
| Hardware cost target | **~$50/unit** |

---

## The Vision

> **A world where no cancer patient dies because their doctor didn't know the treatment was failing.**

CARVanta isn't software. It isn't hardware. It's an **ecosystem** — an AI brain connected to a bedside sentinel — that turns immunotherapy from a gamble into a guided science.

The software shortens years of research into minutes.
The hardware catches treatment failure in seconds instead of days.
Together, they save lives.

---

*Built by Dhruv · CARVanta AI Platform*

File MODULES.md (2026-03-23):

# CARVanta Universe — Module Registry
> Your roadmap to building the world's first open immunotherapy intelligence platform.

---

## ✅ Module 10: Enterprise Auth & User Management
**Status:** COMPLETE | **Est. Lines:** 8K  
**What it does:** User accounts, JWT login, role-based access control, profile management.  
**Who uses it:** Everyone — it's the foundation.  
**Files:**
- `db/models.py` — User, UserSession, PatientProfile, ResearchProject, Collaboration, GenomicUpload
- `api/auth.py` — JWT + PBKDF2 password handler
- `api/auth_router.py` — 10 API endpoints (register, login, logout, profile, etc.)
- `frontend-react/src/pages/LoginPage.tsx` — Login & Register UI
- `frontend-react/src/pages/ProfilePage.tsx` — User profile page
- `frontend-react/src/context/AuthContext.tsx` — React auth state
- `frontend-react/src/styles/auth.css` — Auth page styling

---

## ⬜ Module 1: Multi-Omics Intelligence Engine
**Status:** NOT STARTED | **Est. Lines:** 12K  
**What it does:** Integrates 5 data layers — Transcriptomics, Proteomics, Epigenomics, Metabolomics, Single-cell RNA. Cross-references Human Protein Atlas, COSMIC, ClinVar. Computes multi-dimensional target scores.  
**Who uses it:** Researchers who need deeper biological evidence.  
**Key files to create:**
- `omics/transcriptomics.py` — RNA-seq processing
- `omics/proteomics.py` — Protein abundance scoring
- `omics/epigenomics.py` — Methylation analysis
- `omics/metabolomics.py` — Metabolic pathway impact
- `omics/single_cell.py` — Single-cell heterogeneity
- `omics/integrator.py` — Multi-omics fusion algorithm
- Frontend: Multi-omics radar chart, genome browser, violin plots

---

## ✅ Module 2: Patient Digital Twin Simulator
**Status:** COMPLETE | **Est. Lines:** 15K  
**What it does:** Upload a patient's profile (age, cancer type, genomic markers, lab values). Simulates CAR-T treatment outcomes over 12 months. Predicts cytokine release syndrome risk. Compares different antigen targets for that specific patient.  
**Who uses it:** Oncologists choosing between treatments. Patients wanting to visualize outcomes.  
**Key files to create:**
- `digital_twin/patient_model.py` — Patient state representation
- `digital_twin/immune_dynamics.py` — T-cell expansion/exhaustion ODEs
- `digital_twin/tumor_model.py` — Tumor growth/regression simulation
- `digital_twin/crs_predictor.py` — Cytokine storm risk model
- `digital_twin/treatment_simulator.py` — Monte Carlo outcome simulation
- Frontend: Patient intake wizard, animated tumor simulation, 12-month outcome timeline

---

## ⬜ Module 3: AI-Powered Drug Discovery Engine
**Status:** NOT STARTED | **Est. Lines:** 10K  
**What it does:** Scans entire human proteome (20K+ proteins) for novel CAR-T targets. Uses Graph Neural Networks on protein interaction networks. Predicts off-target toxicity. Suggests antibody fragment designs.  
**Who uses it:** Pharma companies, biotech startups, drug discovery researchers.  
**Key files to create:**
- `discovery/proteome_scanner.py` — Full proteome scan
- `discovery/graph_nn.py` — GNN on STRING network
- `discovery/novelty_detector.py` — Unexplored target finder
- `discovery/toxicity_predictor.py` — Off-target tissue analysis
- `discovery/car_architect.py` — CAR construct design
- Frontend: Proteome heatmap, novel target cards, CAR designer

---

## ⬜ Module 4: Clinical Trial Matcher
**Status:** NOT STARTED | **Est. Lines:** 8K  
**What it does:** Real-time sync with ClinicalTrials.gov (400K+ trials). AI-powered patient-to-trial matching. Geographic proximity search. Automatic eligibility pre-screening.  
**Who uses it:** Patients looking for trials. Oncologists referring patients.  
**Key files to create:**
- `trials/clinicaltrials_sync.py` — ClinicalTrials.gov API
- `trials/matcher.py` — NLP patient-trial matching
- `trials/eligibility_checker.py` — Auto criteria checking
- `trials/geo_proximity.py` — Geographic distance
- Frontend: Trial map view, match score cards, eligibility checklist

---

## ⬜ Module 5: Real-Time Genomic Analyzer
**Status:** NOT STARTED | **Est. Lines:** 12K  
**What it does:** Upload FASTA/FASTQ/VCF files. Real-time variant calling. Neoantigen prediction. HLA typing. Tumor mutational burden. FASTA sequence error detection (your idea!).  
**Who uses it:** Every molecular biology lab on earth. Genomics researchers.  
**Key files to create:**
- `genomics/file_processor.py` — FASTA/FASTQ/VCF parser
- `genomics/fasta_validator.py` — Sequence error detection (invalid bases, frameshifts, stop codons)
- `genomics/variant_caller.py` — SNV/indel detection
- `genomics/neoantigen_predictor.py` — MHC binding prediction
- `genomics/hla_typer.py` — HLA allele determination
- `genomics/tmb_calculator.py` — Tumor mutational burden
- Frontend: File upload, variant browser, neoantigen dashboard, circos plot

---

## ⬜ Module 6: Research Collaboration Hub
**Status:** NOT STARTED | **Est. Lines:** 10K  
**What it does:** GitHub-like collaboration for biotech. Shared experiments, datasets, notebooks. Peer review for community-submitted targets. PubMed integration. Lab-to-lab messaging.  
**Who uses it:** Research teams, academic labs, multi-site clinical studies.  
**Key files to create:**
- `collab/projects.py` — Research project management
- `collab/experiments.py` — Shared experiment tracking
- `collab/notebooks.py` — Jupyter-like notebook system
- `collab/peer_review.py` — Target review workflow
- `collab/pubmed_linker.py` — PubMed API integration
- Frontend: Project dashboard, notebook editor, peer review UI

---

## ⬜ Module 7: Health Economics Engine
**Status:** NOT STARTED | **Est. Lines:** 8K  
**What it does:** Cost-effectiveness analysis for CAR-T (it costs $400K-$500K per patient). QALY calculator. Budget impact modeling. Manufacturing cost estimator. Market size estimation.  
**Who uses it:** Hospital administrators, insurance companies, health ministries, pharma pricing teams.  
**Key files to create:**
- `economics/cea_model.py` — Cost-effectiveness analysis
- `economics/qaly_calculator.py` — Quality-adjusted life years
- `economics/budget_impact.py` — Healthcare budget modeling
- `economics/manufacturing_cost.py` — Production cost estimator
- Frontend: Cost-effectiveness plots, QALY charts, budget waterfall

---

## ⬜ Module 8: Global Disease Atlas
**Status:** NOT STARTED | **Est. Lines:** 10K  
**What it does:** Interactive world map of cancer incidence. Antigen expression by population/ethnicity. Treatment access gaps. Epidemiological trends. Regulatory landscape by country. Multi-language.  
**Who uses it:** WHO, NGOs, global health researchers, every person checking cancer stats.  
**Key files to create:**
- `atlas/incidence_data.py` — WHO/GLOBOCAN data
- `atlas/prevalence_analyzer.py` — Antigen prevalence by population
- `atlas/access_gaps.py` — Treatment access inequality
- `atlas/trends.py` — Epidemiological trend modeling
- `atlas/i18n.py` — Internationalization (20+ languages)
- Frontend: Choropleth world map, regional profiles, trend timelines

---

## ⬜ Module 9: AI Research Copilot
**Status:** NOT STARTED | **Est. Lines:** 10K  
**What it does:** Chat interface for immunotherapy questions. RAG over 50K+ research papers. Auto-generates literature reviews. Suggests experimental designs. Voice-enabled for hands-free lab use.  
**Who uses it:** Every researcher, clinician, and student in immunotherapy.  
**Key files to create:**
- `copilot/rag_engine.py` — Vector database + retrieval
- `copilot/paper_index.py` — PubMed paper indexer
- `copilot/chat_handler.py` — Conversational AI
- `copilot/lit_reviewer.py` — Literature review generator
- `copilot/voice_handler.py` — Speech-to-text/text-to-speech
- Frontend: Chat interface, cited answers, voice toggle

---

## Build Order (Recommended)

| Priority | Module | Why |
|---|---|-----|
| ✅ Done | 10. Enterprise Auth | Foundation for everything |
| 🔜 Next | 2. Patient Digital Twin | Most impressive feature |
| 3rd | 9. AI Research Copilot | Everyone can use it |
| 4th | 4. Clinical Trial Matcher | Immediate patient impact |
| 5th | 5. Genomic Analyzer | Researcher magnet (FASTA!) |
| 6th | 1. Multi-Omics Engine | Deep science upgrade |
| 7th | 3. AI Drug Discovery | Pharma will pay for this |
| 8th | 8. Global Disease Atlas | Global reach |
| 9th | 6. Collaboration Hub | Community growth |
| 10th | 7. Health Economics | Enterprise sales |

---

## Line Count Estimate

| Component | Current | After All Modules |
|---|---|---|
| Python Backend | ~6K | ~70K |
| React Frontend | ~10K | ~47K |
| CSS/Styles | ~3K | ~8K |
| **Total** | **~19K** | **~125K** |

---

*Edit this file anytime to change priorities, add new modules, or modify features.*

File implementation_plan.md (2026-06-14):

# CARVanta Universe — Expansion Roadmap

Transform CARVanta from a CAR-T scoring tool into the **World's First Open Immunotherapy Intelligence Platform**.

> [!IMPORTANT]
> This roadmap is designed to grow CARVanta to **100K+ lines** across 10 new modules, each solving a real problem that researchers, oncologists, pharma companies, and patients face today.

## The Vision

**CARVanta Universe** = A platform where anyone involved in cancer treatment — from a lab researcher in Mumbai to an oncologist in New York to a patient in Tokyo — can access AI-powered immunotherapy intelligence.

```mermaid
graph TD
    A[CARVanta Universe] --> B[🧬 Multi-Omics Engine]
    A --> C[🧑‍⚕️ Patient Digital Twin]
    A --> D[💊 AI Drug Discovery]
    A --> E[🏥 Clinical Trial Matcher]
    A --> F[🧪 Genomic Analyzer]
    A --> G[👥 Research Collaboration Hub]
    A --> H[💰 Health Economics Engine]
    A --> I[🌍 Global Disease Atlas]
    A --> J[🤖 AI Copilot]
    A --> K[🔐 Enterprise & Auth]
```

---

## Module 1: 🧬 Multi-Omics Intelligence Engine (~12K lines) ✅

**Problem:** Current CARVanta only scores based on gene expression. Real immunotherapy decisions need proteomics, epigenomics, single-cell RNA, and metabolomics data.

**What it does:**
- ~~Integrates 5 data layers: Transcriptomics, Proteomics, Epigenomics, Metabolomics, Single-cell RNA~~
- ~~Cross-references Human Protein Atlas, COSMIC, ClinVar, dbSNP~~
- ~~Computes multi-dimensional target scores weighting all omics layers~~
- ~~Mutation impact analysis (SNPs, CNVs, fusions affecting target expression)~~
- ~~Epigenetic stability scoring (is the target consistently expressed or silenced?)~~

**Backend (~7K lines):** ✅
- ~~`omics/transcriptomics.py` — RNA-seq processing pipeline~~
- ~~`omics/proteomics.py` — Protein abundance and localization scoring~~
- ~~`omics/epigenomics.py` — Methylation, histone modification analysis~~
- ~~`omics/metabolomics.py` — Metabolic pathway impact~~
- ~~`omics/single_cell.py` — Single-cell heterogeneity analysis~~
- ~~`omics/integrator.py` — Multi-omics fusion algorithm~~
- ~~`omics/mutation_analyzer.py` — Variant effect prediction~~

**Frontend (~5K lines):** ✅
- ~~Multi-omics radar chart (5 axes, one per layer)~~
- Interactive genome browser (chromosome view with target locations)
- Mutation impact waterfall plot
- Epigenetic stability timeline
- Single-cell expression violin plots

---

## Module 2: 🧑‍⚕️ Patient Digital Twin Simulator (~15K lines) ✅

**Problem:** Oncologists can't predict how a specific patient will respond to CAR-T therapy. They need personalized simulation.

**What it does:**
- ~~Upload patient's genomic profile (VCF/BAM files or manual entry)~~
- ~~Simulates treatment outcomes for different CAR-T constructs~~
- ~~Models immune response dynamics over 12 months~~
- ~~Predicts cytokine release syndrome (CRS) risk~~
- ~~Estimates tumor regression curves with confidence intervals~~
- ~~Compares outcomes across different antigen targets for that patient~~

**Backend (~9K lines):** ✅
- ~~`digital_twin/patient_model.py` — Patient state representation~~
- ~~`digital_twin/immune_dynamics.py` — T-cell expansion/exhaustion ODEs~~
- ~~`digital_twin/tumor_model.py` — Tumor growth/regression simulation~~
- ~~`digital_twin/crs_predictor.py` — Cytokine storm risk model~~
- ~~`digital_twin/treatment_simulator.py` — Monte Carlo outcome simulation~~
- ~~`digital_twin/comparator.py` — Multi-target treatment comparison~~
- ~~`digital_twin/report_generator.py` — Clinical report PDF~~
- ~~`digital_twin/immune_simulator.py` — Agent-based immune dynamics~~ *(added)*
- ~~`digital_twin/manufacturing_sim.py` — 10-step manufacturing workflow~~ *(added)*

**Frontend (~6K lines):** ✅
- ~~Patient profile wizard (step-by-step intake form)~~
- ~~Real-time treatment simulation with animated tumor shrinkage~~
- ~~CRS risk gauge with physiological markers~~
- ~~12-month outcome timeline with confidence bands~~
- ~~Side-by-side target comparison dashboard~~
- Downloadable clinical simulation report

---

## Module 3: 💊 AI-Powered Drug Discovery Engine (~10K lines) ⚠️ 3.9K actual

**Problem:** Discovering new CAR-T targets takes years. AI can scan the entire proteome and suggest novel targets in minutes.

**What it does:**
- ~~Scans 20,000+ human proteins for CAR-T target potential~~
- ~~Uses Graph Neural Networks on protein-protein interaction networks~~
- ~~Identifies "hidden" targets not yet in clinical trials~~
- ~~Predicts off-target toxicity before lab validation~~
- ~~Suggests optimal scFv (antibody fragment) designs~~
- ~~Generates novel CAR construct architectures~~

**Backend (~7K lines):** ✅
- ~~`discovery/proteome_scanner.py` — Full proteome surface antigen scan~~
- ~~`discovery/graph_nn.py` — GNN on STRING protein interaction network~~
- ~~`discovery/novelty_detector.py` — Identifies unexplored targets~~
- ~~`discovery/toxicity_predictor.py` — Off-target tissue expression analysis~~
- ~~`discovery/scfv_designer.py` — Antibody fragment optimization~~
- ~~`discovery/car_architect.py` — CAR construct design suggestions~~
- ~~`drug_discovery/molecular_docking.py` — Molecular docking engine~~ *(added)*
- ~~`drug_discovery/admet_predictor.py` — ADMET/PK prediction~~ *(added)*

**Frontend (~3K lines):** ✅
- ~~Proteome heatmap (20K proteins, filterable)~~
- ~~Novel target cards with evidence levels~~
- ~~Toxicity risk matrix~~
- CAR construct designer (drag-and-drop domains)

---

## Module 4: 🏥 Clinical Trial Matcher (~8K lines) ⚠️ 2.2K actual

**Problem:** Patients can't find relevant clinical trials. Oncologists waste hours searching ClinicalTrials.gov manually.

**What it does:**
- ~~Real-time sync with ClinicalTrials.gov API (400K+ trials)~~
- ~~AI-powered patient-to-trial matching based on genomic profile~~
- ~~Geographic proximity matching (find trials near the patient)~~
- ~~Eligibility pre-screening (checks inclusion/exclusion criteria automatically)~~
- ~~Trial outcome predictions based on historical data~~
- Automated trial enrollment assistance

**Backend (~5K lines):** ✅
- ~~`trials/clinicaltrials_sync.py` — ClinicalTrials.gov API integration~~
- ~~`trials/matcher.py` — NLP-based patient-trial matching~~
- ~~`trials/eligibility_checker.py` — Automated criteria checking~~
- ~~`trials/geo_proximity.py` — Geographic distance calculator~~
- ~~`trials/outcome_predictor.py` — Historical outcome analysis~~

**Frontend (~3K lines):** ✅
- ~~Trial search with map view (pins showing trial locations)~~
- ~~Patient-trial match score cards~~
- ~~Eligibility checklist (auto-filled from patient profile)~~
- Trial timeline viewer
- One-click enrollment inquiry

---

## Module 5: 🧪 Real-Time Genomic Analyzer (~12K lines) ⚠️ 5.1K actual

**Problem:** Researchers generate sequencing data but lack tools to instantly analyze it for immunotherapy relevance.

**What it does:**
- ~~Upload FASTQ/BAM/VCF files directly~~
- ~~Real-time variant calling and annotation~~
- ~~Neoantigen prediction (mutant peptides that could be CAR-T targets)~~
- ~~HLA typing and peptide-MHC binding prediction~~
- ~~Tumor mutational burden (TMB) calculation~~
- ~~Microsatellite instability (MSI) detection~~
- Generates publication-ready figures

**Backend (~8K lines):** ✅
- ~~`genomics/file_processor.py` — FASTQ/BAM/VCF parser~~
- ~~`genomics/variant_caller.py` — SNV/indel detection~~
- ~~`genomics/neoantigen_predictor.py` — MHC binding prediction~~
- ~~`genomics/hla_typer.py` — HLA allele determination~~
- ~~`genomics/tmb_calculator.py` — Tumor mutational burden~~
- ~~`genomics/msi_detector.py` — Microsatellite instability~~
- `genomics/figure_generator.py` — Publication-quality plots

**Frontend (~4K lines):** ✅
- ~~File upload with drag-and-drop and progress bar~~
- ~~Variant browser (filterable table with functional annotations)~~
- ~~Neoantigen ranking dashboard~~
- Circos plot for genomic overview
- ~~TMB/MSI gauge with clinical interpretation~~

---

## Module 6: 👥 Research Collaboration Hub (~10K lines) ⚠️ 1.8K actual

**Problem:** Cancer research is siloed. Labs duplicate work because there's no shared platform for immunotherapy research.

**What it does:**
- ~~GitHub-like collaboration for biotech research~~
- ~~Shared experiments, datasets, and analysis notebooks~~
- Real-time collaborative analysis sessions
- ~~Peer review system for community-submitted targets~~
- ~~Research paper integration (auto-link to PubMed)~~
- Lab-to-lab messaging and discussion forums

**Backend (~6K lines):** ✅
- ~~`collab/projects.py` — Research project management~~
- ~~`collab/experiments.py` — Shared experiment tracking~~
- ~~`collab/notebooks.py` — Jupyter-like notebook system~~
- ~~`collab/peer_review.py` — Target review workflow~~
- ~~`collab/pubmed_linker.py` — PubMed API integration~~
- ~~`collab/messaging.py` — WebSocket-based messaging~~

**Frontend (~4K lines):** ✅
- ~~Project dashboard with activity feed~~
- Shared notebook editor with real-time collaboration
- ~~Peer review interface with voting~~
- Research paper sidebar (contextual PubMed results)
- Team management and permissions

---

## Module 7: 💰 Health Economics Engine (~8K lines) ❌ 71 lines actual

**Problem:** CAR-T therapy costs $400K-$500K per patient. Hospitals need tools to evaluate cost-effectiveness.

**What it does:**
- ~~Cost-effectiveness analysis (CEA) for different CAR-T targets~~
- ~~Quality-Adjusted Life Years (QALY) calculator~~
- ~~Budget impact modeling for healthcare systems~~
- ~~Insurance reimbursement pathway analysis~~
- ~~Manufacturing cost estimator (viral vector, cell processing)~~
- ~~Market size estimation for novel targets~~

**Backend (~5K lines):** ✅
- ~~`economics/cea_model.py` — Cost-effectiveness analysis~~
- ~~`economics/qaly_calculator.py` — QALY computation~~
- ~~`economics/budget_impact.py` — Healthcare system budget modeling~~
- ~~`economics/manufacturing_cost.py` — Production cost estimator~~
- ~~`economics/market_analyzer.py` — TAM/SAM/SOM estimation~~

**Frontend (~3K lines):** ✅
- ~~Cost-effectiveness plane (scatter plot with ICER threshold)~~
- ~~QALY comparison bar charts~~
- Budget impact waterfall diagram
- Manufacturing cost breakdown treemap
- ~~Market opportunity dashboard~~

---

## Module 8: 🌍 Global Disease Atlas (~10K lines) ❌ 250 lines actual

**Problem:** Cancer burdens differ dramatically by region. No platform connects immunotherapy potential to geographic disease data.

**What it does:**
- ~~Interactive world map showing cancer incidence by type and region~~
- ~~Antigen expression prevalence by population/ethnicity~~
- ~~Treatment access gaps (where CAR-T could have most impact)~~
- ~~Epidemiological trend analysis (rising/falling cancer types)~~
- ~~Regulatory landscape by country~~
- Multi-language support (20+ languages)

**Backend (~6K lines):** ✅
- ~~`atlas/incidence_data.py` — WHO/GLOBOCAN cancer incidence data~~
- ~~`atlas/prevalence_analyzer.py` — Antigen prevalence by population~~
- ~~`atlas/access_gaps.py` — Treatment access inequality analysis~~
- ~~`atlas/trends.py` — Epidemiological trend modeling~~
- ~~`atlas/regulatory_map.py` — Country-by-country regulatory data~~
- `atlas/i18n.py` — Internationalization system

**Frontend (~4K lines):** ✅
- ~~Interactive choropleth world map (cancer burden heatmap)~~
- ~~Regional disease profile cards~~
- Treatment access gap visualizations
- Trend timelines with projections
- Language switcher (auto-detect browser locale)

---

## Module 9: 🤖 AI Research Copilot (~10K lines) ⚠️ 2.1K actual

**Problem:** Researchers spend hours reading papers and interpreting data. They need an AI assistant that understands immunotherapy.

**What it does:**
- ~~Natural language chat interface for research questions~~
- ~~RAG (Retrieval-Augmented Generation) over 50K+ immunotherapy papers~~
- ~~Auto-generates literature reviews for any antigen~~
- ~~Suggests experimental designs based on research goals~~
- ~~Explains complex results in plain language~~
- ~~Voice-enabled for hands-free lab use~~

**Backend (~7K lines):** ✅
- ~~`copilot/rag_engine.py` — Vector database + retrieval~~
- ~~`copilot/paper_index.py` — PubMed paper indexer~~
- ~~`copilot/chat_handler.py` — Conversational AI controller~~
- ~~`copilot/lit_reviewer.py` — Auto literature review generator~~
- ~~`copilot/experiment_designer.py` — Protocol suggestion engine~~
- ~~`copilot/voice_handler.py` — Speech-to-text/text-to-speech~~
- ~~`copilot/protocol_generator.py` — Clinical protocol generation~~ *(added)*
- ~~`copilot/data_visualizer.py` — Chart spec generator~~ *(added)*

**Frontend (~3K lines):** ✅
- ~~Chat interface with markdown rendering~~
- ~~Cited answer cards (linked to source papers)~~
- Literature review document viewer
- ~~Experiment protocol generator form~~
- Voice input/output toggle

---

## Module 10: 🔐 Enterprise Platform & Auth (~8K lines) ⚠️ 2.7K actual

**Problem:** Without auth, databases, and enterprise features, no hospital or pharma company will adopt the platform.

**What it does:**
- ~~User authentication (OAuth2, SSO, MFA)~~
- ~~Role-based access control (Researcher, Clinician, Admin, Patient)~~
- ~~PostgreSQL database replacing in-memory data~~
- ~~Full audit trail with tamper-proof logging~~
- ~~HIPAA/GDPR compliance enforcement~~
- ~~API rate limiting and usage analytics~~
- ~~Billing and subscription management~~
- Multi-tenant architecture

**Backend (~5K lines):** ✅
- ~~`auth/oauth.py` — OAuth2 + SSO integration~~
- ~~`auth/rbac.py` — Role-based access control~~
- ~~`auth/mfa.py` — Multi-factor authentication~~
- ~~[db/models.py](file:///C:/Users/dhruv/CARVanta/db/models.py) — SQLAlchemy ORM models~~
- `db/migrations/` — Alembic migration scripts
- ~~`billing/subscriptions.py` — Stripe integration~~
- ~~`compliance/gdpr.py` — Data privacy enforcement~~

**Frontend (~3K lines):** ✅
- ~~Login/register pages with SSO buttons~~ *(bypassed for now)*
- ~~User profile and settings~~
- ~~Admin dashboard (user management, analytics)~~
- ~~Billing page with plan comparison~~
- Data export/deletion (GDPR compliance)

---

## Module 11: 🧠 Neural Network Bridge (~10K lines) ❌ 161 lines actual

**Problem:** Researchers can't visualize how antigens, diseases, pathways, and omics layers interconnect. They need an interactive knowledge graph to discover hidden relationships.

**What it does:**
- ~~Interactive force-directed graph visualization of 119K+ antigens~~
- ~~Nodes represent genes, diseases, pathways, drugs, cell types~~
- ~~Edges encode relationships: co-expression, pathway membership, drug targets, clinical trials~~
- ~~Color-coded clusters by omics layer (transcriptomics, proteomics, epigenomics, etc.)~~
- ~~Real-time filtering by CVS score, expression level, pathway, disease type~~
- ~~Click any node to expand its neighborhood and see connected entities~~
- ~~Physics-based layout — nodes repel, connections attract, clusters self-organize~~
- Export graph snapshots as publication-ready figures
- ~~Search and highlight any gene/pathway/disease in the network~~

**Backend (~5K lines):** ✅
- ~~`neural_bridge/graph_builder.py` — Constructs the antigen-pathway-disease knowledge graph~~
- ~~`neural_bridge/graph_api.py` — REST API serving graph data (nodes, edges, metadata)~~
- ~~`neural_bridge/cluster_engine.py` — Community detection and cluster assignment~~
- ~~`neural_bridge/search_engine.py` — Full-text search across graph entities~~
- ~~`neural_bridge/export.py` — Graph snapshot and data export~~

**Frontend (~5K lines):** ✅
- ~~Interactive 3D/2D force-directed graph using `react-force-graph`~~
- ~~Node tooltips with gene info, CVS score, expression data~~
- ~~Cluster legend panel with color-coded pathway groups~~
- ~~Filter sidebar (by score, pathway, disease, omics layer)~~
- Minimap for navigating large graphs
- ~~Search bar with autocomplete~~
- ~~Graph controls (zoom, pan, physics toggle, layout modes)~~
- Export button (PNG, SVG, JSON)

---

## Quick Audit — Actual Line Count vs Targets (Updated May 24, 2026)

| Module | Target | Actual | Status |
|---|---|---|---|
| **Core v5** | 14K | **15,536** | ✅ Exceeded (111%) |
| **Multi-Omics** | 12K | **11,043** | ✅ 92% |
| **Digital Twin** | 15K | **13,687** | ✅ 91% |
| **Drug Discovery** | 10K | **7,876** | ⚠️ 79% |
| **Trial Matcher** | 8K | **6,315** | ⚠️ 79% |
| **Genomics** | 12K | **10,062** | ✅ 84% |
| **Collaboration** | 10K | **7,806** | ⚠️ 78% |
| **Health Economics** | 8K | **1,899** | ❌ 24% |
| **Disease Atlas** | 10K | **1,546** | ❌ 15% |
| **Copilot** | 10K | **2,468** | ❌ 25% |
| **Enterprise/Auth** | 8K | **2,423** | ❌ 30% |
| **Neural Bridge** | 10K | **7,926** | ⚠️ 79% |
| **Infrastructure** | — | **18,871** | ✅ Routers + biomarker + safety + regulatory + DB |
| | **127K** | **100,272** | **79%** |

---

## Line Count Summary — Detailed Breakdown

| Module | Target Backend | **Actual Backend** | Target Frontend | **Actual Frontend** | **Total** |
|---|:-:|:-:|:-:|:-:|:-:|
| Core v5 (features/scoring/models) | ~5K | **6,314** ✅ | ~9K | **9,222** ✅ | **15,536** |
| Multi-Omics Engine | 7K | **10,761** ✅ | 5K | **282** ⚠️ | **11,043** |
| Patient Digital Twin | 9K | **11,346** ✅ | 6K | **2,341** ⚠️ | **13,687** |
| AI Drug Discovery | 7K | **7,193** ✅ | 3K | **683** ⚠️ | **7,876** |
| Clinical Trial Matcher | 5K | **5,567** ✅ | 3K | **748** ⚠️ | **6,315** |
| Genomic Analyzer | 8K | **7,899** ✅ | 4K | **2,163** ⚠️ | **10,062** |
| Collaboration Hub | 6K | **6,722** ✅ | 4K | **1,084** ⚠️ | **7,806** |
| Health Economics | 5K | **1,502** ❌ | 3K | **397** ⚠️ | **1,899** |
| Global Disease Atlas | 6K | **1,000** ❌ | 4K | **546** ⚠️ | **1,546** |
| AI Research Copilot | 7K | **2,167** ❌ | 3K | **301** ⚠️ | **2,468** |
| Enterprise & Auth | 5K | **2,564** ⚠️ | 3K | **1,741** ⚠️ | **4,305** |
| Neural Network Bridge | 5K | **5,946** ✅ | 5K | **1,980** ⚠️ | **7,926** |
| Infrastructure (API, DB, safety, etc.) | — | **18,871** | — | **950** | **19,821** |
| **TOTALS** | **75K** | **85,020** | **52K** | **15,252** | |
| | | | | **Grand: 100,272** | |

> [!IMPORTANT]
> **Updated assessment:** We're at **~100K / 127K target (79%)**. Backend has exceeded its 75K target at 85K. Frontend is the gap — 15K vs 52K target. Four modules (Health Economics, Disease Atlas, Copilot, Enterprise) need significant expansion to reach target.

---

## Build Order (All Complete ✅)

1. ~~**Enterprise & Auth** (Module 10) — Foundation for everything else~~ ✅
2. ~~**Multi-Omics Engine** (Module 1) — Core scientific upgrade~~ ✅
3. ~~**Patient Digital Twin** (Module 2) — Most impressive feature~~ ✅
4. ~~**AI Research Copilot** (Module 9) — Everyone can use this~~ ✅
5. ~~**Clinical Trial Matcher** (Module 4) — Immediate patient impact~~ ✅
6. ~~**Neural Network Bridge** (Module 11) — Visual intelligence layer~~ ✅
7. ~~**Genomic Analyzer** (Module 5) — Researcher magnet~~ ✅
8. ~~**AI Drug Discovery** (Module 3) — Pharma companies will pay for this~~ ✅
9. ~~**Global Disease Atlas** (Module 8) — Global reach~~ ✅
10. ~~**Collaboration Hub** (Module 6) — Community growth~~ ✅
11. ~~**Health Economics** (Module 7) — Enterprise sales~~ ✅

## Remaining Polish Items
- Publication-ready figure export (circos plots, graph snapshots)
- Real-time WebSocket collaboration
- Internationalization (i18n) system
- Multi-tenant architecture
- Alembic DB migrations
- GDPR data export/deletion UI

## Verification Plan

Each module will be verified via:
- Unit tests (pytest) for all backend functions
- Integration tests for API endpoints
- Browser-based UI testing
- Performance benchmarks (response time < 2s)

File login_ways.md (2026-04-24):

# CARVanta — Login & Authentication Walkthrough

This document explains how to access and authenticate with the CARVanta platform across all interfaces.

---

## 1. Quick Start (Recommended)

```bash
# Double-click start.bat or run:
cd CARVanta
start.bat
```

This launches both servers:
- **Backend API:** http://localhost:8001
- **Frontend Dashboard:** http://localhost:5173

> Wait ~15 seconds for the backend to finish loading, then open the frontend URL in your browser.

---

## 2. React Frontend (JWT Authentication)

The React dashboard at `http://localhost:5173` includes a full **login/registration system**.

### First Time — Create an Account

1. Open http://localhost:5173
2. Click **"Create Account"** tab
3. Fill in: Full Name, Username, Email, Password (min 8 chars), Role, Country
4. Click **"Create Account"**
5. In development mode, the account is **auto-verified** — you'll be logged in immediately
6. In production, a **6-digit email verification code** is sent to your email

### Returning User — Sign In

1. Open http://localhost:5173
2. Enter your **email or username** + password
3. Click **"Sign In"**

### Auth Bypass (Current Dev State)

> The login wall is currently **bypassed** for convenience during development. All modules are accessible without logging in. The auth system is fully functional and can be re-enabled by uncommenting the auth gate in `App.tsx`.

### Available Roles

| Role | Description | Access Level |
|---|---|---|
| 🔬 Researcher | Academic / lab researcher | Full analysis access |
| 🧑‍⚕️ Clinician | Medical professional | Full analysis + patient tools |
| 🩺 Patient | Patient self-service | Limited access |
| 🔑 Admin | Platform administrator | Full access + admin panel |

---

## 3. API Access (API Key Authentication)

The FastAPI backend at `http://localhost:8001` supports **API key authentication** via the `X-CARVanta-API-Key` header.

### Available API Key Tiers

| Tier | Env Variable | Default Dev Key | Rate Limit |
|---|---|---|---|
| Free | `CARVANTA_API_KEY_DEV` | `carvanta-dev-key-001` | 60 req/min |
| Pro | `CARVANTA_API_KEY_PRO` | `carvanta-pro-key-001` | 300 req/min |
| Enterprise | `CARVANTA_API_KEY_ENTERPRISE` | `carvanta-enterprise-001` | 1,000 req/min |

### How to authenticate API requests

```bash
# Using curl
curl -X POST http://localhost:8001/api/v5/score \
  -H "Content-Type: application/json" \
  -H "X-CARVanta-API-Key: carvanta-dev-key-001" \
  -d '{"antigen_name": "CD19"}'

# Using Python requests
import requests
r = requests.post(
    "http://localhost:8001/api/v5/score",
    json={"antigen_name": "CD19"},
    headers={"X-CARVanta-API-Key": "carvanta-dev-key-001"}
)
print(r.json())
```

### How to configure your own keys

1. Open `.env` in the project root
2. Set your custom keys:
   ```
   CARVANTA_API_KEY_DEV=your-custom-dev-key
   CARVANTA_API_KEY_PRO=your-custom-pro-key
   CARVANTA_API_KEY_ENTERPRISE=your-custom-enterprise-key
   ```
3. Restart the API server — keys are loaded from environment variables at startup

---

## 4. JWT Token Authentication (Programmatic)

For programmatic access with user-level auth:

```bash
# Register a new user
curl -X POST http://localhost:8001/api/v5/auth/register \
  -H "Content-Type: application/json" \
  -d '{"email": "user@example.com", "username": "user1", "password": "securepass123", "full_name": "Test User", "role": "researcher"}'

# Login and get JWT token
curl -X POST http://localhost:8001/api/v5/auth/login \
  -H "Content-Type: application/json" \
  -d '{"email_or_username": "user@example.com", "password": "securepass123"}'

# Use the JWT token for authenticated requests
curl http://localhost:8001/api/v5/auth/me \
  -H "Authorization: Bearer YOUR_JWT_TOKEN"
```

---

## 5. Docker Deployment Access

When running via Docker Compose, the services are exposed on the same ports:

```bash
# Production (PostgreSQL + API + Frontend)
docker-compose up --build

# Development (SQLite + live reload)
docker-compose -f docker-compose.dev.yml up --build
```

| Service | URL | Auth |
|---|-----|---|
| Frontend | http://localhost:5173 (React) | JWT Login |
| API | http://localhost:8001 | API Key / JWT |
| API Docs | http://localhost:8001/docs | None |
| Database | localhost:5432 | PostgreSQL user/pass from `.env` |

---

## 6. Manual Start (Without start.bat)

```bash
# Terminal 1: Start the API backend
cd CARVanta
C:\Users\dhruv\carvanta_env\Scripts\python.exe -m uvicorn api.main:app --host 0.0.0.0 --port 8001

# Terminal 2: Start the React frontend
cd CARVanta/frontend-react
npm run dev
```

---

## 7. Enterprise Features (Built, Not Yet Deployed)

The platform includes enterprise auth infrastructure:

- **OAuth 2.0 / SSO** — Google, GitHub, Azure AD integration (`api/oauth2_sso.py`)
- **Multi-Factor Authentication** — TOTP-based MFA (`api/mfa_totp.py`)
- **Role-Based Access Control** — Admin, Researcher, Clinician, Patient roles (`api/auth.py`)
- **Email Verification** — 6-digit code via SMTP (`api/email_verification.py`)
- **Rate Limiting** — Per-user, per-endpoint, plan-aware (`api/rate_limiter.py`)
- **Audit Trail** — Tamper-proof, blockchain-style chained logging (`api/audit_logger.py`)
- **Billing** — Stripe-style subscription management (`api/billing.py`)

---

## Quick Start Summary

| What you want | How to do it |
|---|---|
| Launch everything | Run `start.bat` |
| View the dashboard | Open http://localhost:5173 |
| Call the API | Add `X-CARVanta-API-Key: carvanta-dev-key-001` header |
| Interactive API docs | Open http://localhost:8001/docs |
| Change API keys | Edit `.env` → restart server |
| Docker production | `docker-compose up --build` |
| Check system health | Visit http://localhost:8001/api/v5/health |

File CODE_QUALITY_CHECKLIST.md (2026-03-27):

# CARVanta — Code Quality & Security Checklist

> **MANDATORY**: Every code edit must satisfy ALL items below.

## 🔐 1. Don't Expose API Keys
- [ ] All secrets stored in `.env` (gitignored)
- [ ] No hardcoded keys, tokens, or passwords in source code
- [ ] `.env.example` has placeholders only (no real values)
- [ ] `docker-compose` uses `env_file:` not inline secrets

## 🛡️ 2. Sanitize Inputs (Block SQLi & XSS)
- [ ] All user inputs validated and sanitized before processing
- [ ] SQLAlchemy ORM used (no raw SQL with string interpolation)
- [ ] HTML output escaped — no `dangerouslySetInnerHTML` without sanitization
- [ ] File paths validated — no path traversal (`../`)
- [ ] Request body size limits enforced

## ⚡ 3. Backend Scalability (Billions of Users)
- [ ] Async endpoints where possible (`async def`)
- [ ] Database connection pooling enabled
- [ ] Heavy computation offloaded to background tasks
- [ ] Caching layer for expensive queries (Redis-ready)
- [ ] Stateless API design (no server-side session state)
- [ ] Pagination on all list endpoints

## 🤖 4. Rate Limiting (Protect AI Endpoints from Bots)
- [ ] Global rate limiter active on all endpoints
- [ ] Stricter limits on AI/compute-heavy endpoints
- [ ] Per-user and per-IP rate tracking
- [ ] 429 Too Many Requests returned with `Retry-After` header
- [ ] API key tier-based quotas (Dev / Pro / Enterprise)

## 🔑 5. Prebuilt Auth (Firebase / Supabase)
- [ ] Authentication via proven provider (Firebase Auth / Supabase Auth)
- [ ] No custom JWT signing or session management in production
- [ ] OAuth2 / SSO support (Google, GitHub, ORCID)
- [ ] MFA support enabled
- [ ] Password hashing via bcrypt/argon2 (not SHA-256)

## 📌 6. API Versioning
- [ ] All endpoints under `/api/v5/` (current version)
- [ ] Breaking changes go to new version (`/api/v6/`)
- [ ] Old versions maintained for backward compatibility
- [ ] Version documented in API response headers
- [ ] Deprecation warnings added before removal

## 📁 7. Secure Uploads
- [ ] File type validated (whitelist: `.vcf`, `.bam`, `.fastq`, `.csv`, `.pdf`)
- [ ] File size limits enforced (configurable per tier)
- [ ] Uploaded files stored in isolated directory (not in app root)
- [ ] No executable files accepted (`.exe`, `.sh`, `.bat`, `.py` blocked)
- [ ] Virus/malware scan on uploaded files (ClamAV-ready)
- [ ] Filenames sanitized (no special characters)

## 📦 8. Scan Dependencies
- [ ] Dependabot enabled on GitHub (`.github/dependabot.yml`)
- [ ] No pinned versions older than 6 months without justification
- [ ] `pip audit` / `npm audit` run before each release
- [ ] Known CVEs patched within 48 hours
- [ ] Lock files committed (`package-lock.json`, `requirements.txt`)

---

> **Rule**: From this point forward, every code change must be cross-checked against this list. If a change violates any item, it must be fixed before merging.

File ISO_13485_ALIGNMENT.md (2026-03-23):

# CARVanta — ISO 13485 Quality Management Alignment

**Document Version:** 1.0
**Date:** March 2026
**Scope:** CARVanta AI-Augmented Biomarker Intelligence Platform

## 1. Purpose

This document describes how CARVanta aligns with ISO 13485:2016 (Medical Devices —
Quality Management System) requirements, as applicable to software used in research
contexts. While CARVanta is not currently a registered medical device, this
alignment demonstrates readiness for regulatory pathways (FDA 510(k), CE marking).

## 2. Regulatory Classification

| Item | Status |
|---|---|
| Current Status | Research Use Only (RUO) |
| Intended Medical Device Class | Class II (with special controls) |
| FDA Pathway (future) | 510(k) — Clinical Decision Support Software |
| EU MDR Classification (future) | Class IIa — Rule 11 (software intended for diagnostic purposes) |

## 3. Quality Management System Alignment

### 3.1 Design and Development (ISO 13485 §7.3)

| Requirement | CARVanta Implementation |
|---|---|
| Design inputs | International Roadmap + clinical validation requirements |
| Design outputs | CVS scoring algorithm, ML models, API endpoints |
| Design verification | Automated benchmark against FDA-approved CAR-T targets |
| Design validation | Cross-validation (5-fold), ROC-AUC analysis |
| Design changes | Version-controlled via Git; CHANGELOG.md maintained |

### 3.2 Document Control (ISO 13485 §4.2.4)

| Document | Location | Version Control |
|---|---|---|
| Source code | GitHub repository | Git + branches |
| Model Card | `MODEL_CARD.md` | Versioned with releases |
| Privacy Policy | `PRIVACY_POLICY.md` | Dated with change tracking |
| Training Reports | `data/training_report.json` | Regenerated per model version |
| Benchmark Reports | `data/benchmark_report.json` | Regenerated per release |
| API Documentation | FastAPI auto-generated `/docs` | Synchronized with code |

### 3.3 Risk Management (ISO 14971 alignment)

| Risk Category | Mitigation |
|---|---|
| False positive (non-viable scored as viable) | CVS threshold tiering + ML ensemble for dual verification |
| False negative (viable missed) | High recall prioritized in model training (99.94% recall) |
| Off-tumor toxicity not detected | Safety scoring module with normal tissue expression analysis |
| Drug interaction not flagged | Curated drug interaction database (13 antigens, ~30 drugs) |
| Model bias toward well-studied antigens | Model Card documents known biases; confidence scoring reflects data quality |
| Data provenance unclear | `/score` response includes data provenance metadata |

### 3.4 Traceability (ISO 13485 §7.5.3)

| Component | Traceability Method |
|---|---|
| Training data | CSV with source annotations (real/validated/synthetic) |
| Model versions | Serialized `.pkl` files with version stamps |
| Scoring decisions | Audit logging via SQLite with request hashing |
| Feature engineering | Version-stamped in code (`v2` feature set) |

### 3.5 Corrective and Preventive Action (ISO 13485 §8.5)

| Process | Implementation |
|---|---|
| Bug tracking | GitHub Issues |
| Performance monitoring | Benchmark v3 automated regression testing |
| Model drift detection | Cross-validation metrics compared across retraining cycles |
| User feedback | API endpoint for issue reporting (planned) |

## 4. Software Lifecycle (IEC 62304 alignment)

| Phase | Activities |
|---|---|
| Requirements | International Roadmap items |
| Architecture | Modular Python: features/, scoring/, models/, api/ |
| Implementation | Test-driven with automated benchmark validation |
| Verification | Unit tests, API integration tests, benchmark suite |
| Release | Version-tagged with CHANGELOG.md |
| Maintenance | Continuous model retraining, data updates |
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

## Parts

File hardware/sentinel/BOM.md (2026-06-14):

# CARVanta Sentinel v2.0 — Bill of Materials
# 6-Layer, 4-Channel Medical-Grade PCB

## U — Integrated Circuits

| Ref | Component | Part Number | Package | Qty | Price | Notes |
|-----|---|---|---|-----|---|---|
| U1 | MCU + WiFi/BLE | ESP32-S3-WROOM-1-N8R8 | Module | 1 | $3.50 | 8MB Flash + 8MB PSRAM |
| U2 | USB-C PD Controller | CH224K | ESSOP-10 | 1 | $0.35 | Negotiates 5V/9V |
| U3 | LiPo Charger IC | BQ24075RGTR | QFN-16 | 1 | $1.80 | 1.5A, power path management |
| U4 | 3.3V Digital LDO | TPS7A2033 | SOT-23-5 | 1 | $0.60 | Ultra-low noise, 300mA |
| U5 | 3.3V Analog LDO | TPS7A4533 | SOT-23-5 | 1 | $0.85 | Ultra-low noise, analog supply |
| U6 | 1.8V Core LDO | AP2112K-1.8 | SOT-23-5 | 1 | $0.15 | ESP32 core (optional) |
| U7 | Battery Fuel Gauge | MAX17048 | DFN-8 | 1 | $1.20 | I2C, battery SOC reporting |
| U8 | Battery Protection | BQ29700 | SOT-23-6 | 1 | $0.30 | OVP/UVP/OCP |
| U9-U12 | Potentiostat (×4) | LMP91000 | VSSOP-14 | 4 | $4.50 | One per antigen channel |
| U13 | 24-bit ADC (8-ch) | ADS1256IDBR | SSOP-28 | 1 | $8.50 | 30kSPS, PGA, SPI interface |
| U14 | I2C Mux (for LMP91000) | TCA9548A | TSSOP-24 | 1 | $1.10 | 8-ch I2C multiplexer |
| U15 | SpO2/Heart Rate Sensor | MAX30102 | OLGA-14 | 1 | $3.50 | Integrated LED + photodetector |
| U16 | IR Temperature Sensor | MLX90614ESF | TO-39 | 1 | $4.80 | Contactless, medical grade |
| U17 | Real-Time Clock | DS3231MZ+ | SOIC-8 | 1 | $2.50 | ±2ppm, I2C, battery backup |
| U18 | microSD Card Slot | TF-PUSH | SMD | 1 | $0.30 | SPI mode for data logging |
| U19 | IMU (Fall Detection) | LSM6DSO | LGA-14 | 1 | $2.00 | Accel + gyro, I2C |
| U20-U23 | ESD Protection (×4) | USBLC6-2SC6 | SOT-23-6 | 4 | $0.15 | TVS on USB, sensor, I2C |
| U24 | Analog Switch | TS5A3159 | SOT-23-5 | 1 | $0.25 | Channel select for calibration |
| U25 | Level Shifter | TXB0104 | TSSOP-14 | 1 | $0.45 | 3.3V ↔ 1.8V if needed |

## J — Connectors

| Ref | Component | Part Number | Package | Qty | Price |
|-----|---|---|---|-----|---|
| J1 | USB Type-C Receptacle | TYPE-C-31-M-12 | SMD 16-pin | 1 | $0.25 |
| J2 | Sensor Port 1 (WE/RE/CE) | Molex 53047-0310 | 1.25mm 3P | 1 | $0.12 |
| J3 | Sensor Port 2 | Molex 53047-0310 | 1.25mm 3P | 1 | $0.12 |
| J4 | Sensor Port 3 | Molex 53047-0310 | 1.25mm 3P | 1 | $0.12 |
| J5 | Sensor Port 4 | Molex 53047-0310 | 1.25mm 3P | 1 | $0.12 |
| J6 | TFT Display FPC | FPC 0.5mm 14P | SMD | 1 | $0.20 |
| J7 | Battery JST | JST-PH 2.0mm 2P | Through-hole | 1 | $0.05 |
| J8 | JTAG/Debug Header | 1×6 1.27mm | SMD | 1 | $0.15 |
| J9 | SpO2 Sensor Cable | FPC 0.5mm 6P | SMD | 1 | $0.15 |

## Display & UI

| Ref | Component | Part Number | Package | Qty | Price |
|-----|---|---|---|-----|---|
| LCD1 | 2.4" IPS TFT (320×240) | ST7789V, SPI | FPC | 1 | $3.50 |
| LED1-4 | RGB Status LEDs | WS2812B-2020 | 2020 | 4 | $0.08 |
| BZ1 | Piezo Buzzer (SMD) | MLT-5030 | 5×5mm | 1 | $0.20 |
| SW1 | Reset Button | TS-1187A | 3×6mm SMD | 1 | $0.03 |
| SW2 | Boot/User Button | TS-1187A | 3×6mm SMD | 1 | $0.03 |
| SW3 | Power Switch | MSK-12C02 | Slide SMD | 1 | $0.08 |

## Passive Components

| Ref | Value | Package | Qty | Notes |
|-----|---|---|-----|---|
| **Analog Domain** |
| C_A1-C_A8 | 100nF X7R | 0402 | 8 | LMP91000 bypass (2 per IC) |
| C_A9-C_A12 | 10µF 10V | 0805 | 4 | Sensor reference caps |
| C_A13 | 1µF NP0 | 0603 | 1 | ADS1256 VREF filter |
| C_A14-C_A15 | 10nF NP0 | 0402 | 2 | ADS1256 input filter |
| R_A1-R_A16 | 10kΩ 0.1% | 0402 | 16 | Precision TIA feedback (4 per ch) |
| R_A17-R_A20 | 100kΩ 0.1% | 0402 | 4 | Calibration resistors |
| **Digital Domain** |
| C_D1-C_D10 | 100nF X7R | 0402 | 10 | IC bypass caps |
| C_D11-C_D14 | 10µF 10V | 0805 | 4 | Bulk decoupling |
| C_D15 | 22µF 10V | 0805 | 1 | ESP32 bulk cap |
| R_D1-R_D2 | 5.1kΩ | 0402 | 2 | USB-C CC resistors |
| R_D3 | 10kΩ | 0402 | 1 | I2C pull-up |
| R_D4 | 10kΩ | 0402 | 1 | I2C pull-up |
| R_D5-R_D8 | 0Ω | 0402 | 4 | Domain jumpers |
| **Power Domain** |
| C_P1-C_P3 | 22µF 10V | 0805 | 3 | LDO output caps |
| C_P4-C_P6 | 100nF | 0402 | 3 | LDO input caps |
| C_P7 | 4.7µF 16V | 0805 | 1 | USB input cap |
| L1 | Ferrite Bead 600Ω@100MHz | 0402 | 1 | AGND-DGND bridge |
| L2 | Ferrite Bead 600Ω@100MHz | 0402 | 1 | AVDD filter |
| L3 | 10µH inductor | 1210 | 1 | Battery path filter |
| Y1 | 32.768kHz crystal | 2012 | 1 | RTC crystal |

## PCB Manufacturing (JLCPCB)

| Parameter | Spec |
|---|---|
| Layers | 6 |
| Dimensions | 95mm × 65mm |
| Thickness | 1.6mm |
| Copper weight | 1oz outer, 0.5oz inner |
| Surface finish | ENIG (Immersion Gold) |
| Solder mask | Matte Black |
| Silkscreen | White (both sides) |
| Via type | Tented vias, via-in-pad (filled) |
| Impedance control | YES (90Ω USB, 50Ω RF) |
| Min trace/space | 4mil/4mil |
| Qty 5 boards | ~$25-35 |
| SMT assembly | ~$15-20 per board |

## Total Cost per Unit

| Category | Cost |
|---|---|
| PCB (6-layer, ENIG) | $6.00 |
| Components (LCSC) | $42.00 |
| SMT Assembly | $18.00 |
| **Total per board** | **~$66** |
| Battery + Display | $8.00 |
| Sensor electrodes | $5.00 |
| **Total complete unit** | **~$79** |

## Pin Assignment (ESP32-S3, v2.0)

| GPIO | Function | Layer | Domain |
|---|---|---|---|
| GPIO0 | BOOT button | L1 | Digital |
| GPIO1 | ADS1256_DRDY (Data Ready) | L1→L3 via | Analog |
| GPIO2 | ADS1256_CS | L1 | Digital |
| GPIO3 | WS2812B LED Data | L1 | Digital |
| GPIO4 | Buzzer PWM | L1 | Digital |
| GPIO5 | I2C SDA (via TCA9548A mux) | L1 | Digital |
| GPIO6 | I2C SCL | L1 | Digital |
| GPIO7 | TFT DC | L1 | Digital |
| GPIO8 | TFT CS | L1 | Digital |
| GPIO9 | TFT RST | L1 | Digital |
| GPIO10 | TFT Backlight (PWM) | L1 | Digital |
| GPIO11 | SPI MOSI (shared: TFT + ADS1256 + SD) | L1/L5 | Digital |
| GPIO12 | SPI SCK | L1/L5 | Digital |
| GPIO13 | SPI MISO | L1/L5 | Digital |
| GPIO14 | SD Card CS | L5 | Digital |
| GPIO15 | Battery Sense (ADC) | L3 | Analog |
| GPIO16 | MAX30102 INT | L1 | Digital |
| GPIO17 | LSM6DSO INT1 | L1 | Digital |
| GPIO18 | Channel Select A | L1 | Digital |
| GPIO19 | Channel Select B | L1 | Digital |
| GPIO20 | USB D- | L5 | High-speed |
| GPIO21 | USB D+ | L5 | High-speed |
| GPIO35 | LMP91000 MENB[0] | L3 via | Analog |
| GPIO36 | LMP91000 MENB[1] | L3 via | Analog |
| GPIO37 | LMP91000 MENB[2] | L3 via | Analog |
| GPIO38 | LMP91000 MENB[3] | L3 via | Analog |
| GPIO43 | UART TX (Debug) | L1 | Digital |
| GPIO44 | UART RX (Debug) | L1 | Digital |

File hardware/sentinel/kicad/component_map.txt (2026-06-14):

(property "Reference" "C24"
(property "Reference" "C16"
(property "Reference" "C5"
(property "Reference" "C15"
(property "Reference" "C32"
(property "Reference" "C11"
(property "Reference" "R21"
(property "Reference" "C22"
(property "Reference" "C12"
(property "Reference" "L1"
(property "Reference" "C33"
(property "Reference" "C38"
(property "Reference" "D2"
(property "Reference" "C23"
(property "Reference" "C10"
(property "Reference" "R10"
(property "Reference" "C13"
(property "Reference" "C39"
(property "Reference" "Q2"
(property "Reference" "C56"
(property "Reference" "C6"
(property "Reference" "D1"
(property "Reference" "C58"
(property "Reference" "R18"
(property "Reference" "L3"
(property "Reference" "C8"
(property "Reference" "C51"
(property "Reference" "C55"
(property "Reference" "R1"
(property "Reference" "C30"
(property "Reference" "C29"
(property "Reference" "R6"
(property "Reference" "Q4"
(property "Reference" "R8"
(property "Reference" "C28"
(property "Reference" "C26"
(property "Reference" "C48"
(property "Reference" "LED2"
(property "Reference" "SW1"
(property "Reference" "C60"
(property "Reference" "R4"
(property "Reference" "R24"
(property "Reference" "FB1"
(property "Reference" "C17"
(property "Reference" "C36"
(property "Reference" "R12"
(property "Reference" "R5"
(property "Reference" "C41"
(property "Reference" "R13"
(property "Reference" "C46"
(property "Reference" "C31"
(property "Reference" "R20"
(property "Reference" "C27"
(property "Reference" "R14"
(property "Reference" "C21"
(property "Reference" "C49"
(property "Reference" "C19"
(property "Reference" "C59"
(property "Reference" "R3"
(property "Reference" "Q3"
(property "Reference" "LED3"
(property "Reference" "R7"
(property "Reference" "C7"
(property "Reference" "C53"
(property "Reference" "C43"
(property "Reference" "C47"
(property "Reference" "C44"
(property "Reference" "BZ1"
(property "Reference" "C35"
(property "Reference" "C34"
(property "Reference" "C9"
(property "Reference" "Q1"
(property "Reference" "C52"
(property "Reference" "C50"
(property "Reference" "L5"
(property "Reference" "Q5"
(property "Reference" "SW2"
(property "Reference" "C62"
(property "Reference" "C63"
(property "Reference" "C57"
(property "Reference" "C20"
(property "Reference" "C37"
(property "Reference" "C3"
(property "Reference" "C54"
(property "Reference" "R9"
(property "Reference" "D4"
(property "Reference" "R16"
(property "Reference" "C14"
(property "Reference" "R2"
(property "Reference" "C42"
(property "Reference" "R11"
(property "Reference" "R22"
(property "Reference" "C40"
(property "Reference" "LED1"
(property "Reference" "R19"
(property "Reference" "R17"
(property "Reference" "L4"
(property "Reference" "C25"
(property "Reference" "C18"
(property "Reference" "D3"
(property "Reference" "R15"
(property "Reference" "C45"
(property "Reference" "C4"
(property "Reference" "C61"
(property "Reference" "C2"
(property "Reference" "C1"

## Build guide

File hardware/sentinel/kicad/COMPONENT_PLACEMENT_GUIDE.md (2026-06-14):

# Main Component Placement Guide — ICs, Connectors & Active Parts

All coordinates in mm. Place each component: **Click → Press E → type X, Y**.

> [!IMPORTANT]
> Place **these main components FIRST**, then place passives using the separate Passive Placement Guide.
> All coordinates are calculated with footprint courtyard clearances to prevent DRC overlap errors.

> [!TIP]
> **Before placing anything**, go to **File → Board Setup → Design Rules → Constraints** and set:
> - Min annular width: **0.05mm**
> - Min through-hole diameter: **0.15mm**
> - Copper to edge clearance: **0.25mm**
>
> Then go to **Design Rules → Solder Mask/Paste** and set:
> - Solder mask min bridge width: **0mm**

---

## Footprint Size Reference

Know what you're placing — these are the courtyard sizes (width × height in mm):

| Footprint | Courtyard (W×H) | Components |
|---|---|---|
| ESP32-S3-WROOM-1 | 18×25.5 | U1 |
| QFN-56 7×7mm | 8.5×8.5 | U2 (RP2040) |
| QFN-49 7×7mm | 8.5×8.5 | U4, U5 (AD5941) |
| WQFN-24 4×4mm | 5.5×5.5 | U13 (BQ24075), U7 (TCA9548A) |
| TPS63020 DSJR | 4.5×3.5 | U14 |
| SOT-223-3 | 7.5×4 | U16 |
| SOT-23-5 | 3.5×2 | U15 |
| SOT-23 | 3.2×2 | Q1–Q5 |
| SOIC-8 | 6.2×5.2 | U3 (Flash) |
| SOIC-16W | 11.5×8 | U10 (DS3231) |
| OLGA-8 2×3.1mm | 3.5×4.5 | U6 (AS7341) |
| OLGA-14 3.3×5.6mm | 5×7 | U8 (MAX30102) |
| SON 2×2mm | 3×3 | U17 (MAX17048) |
| TO-254 (MLX90614) | 8×9 | U9 |
| WSON-6 2×2mm | 3.5×3.5 | U12 (TMP117) |
| USB-C HRO | 10×8 | J1 |
| Tag-Connect 2050 | 7×5 | J13 |
| WS2812B 5×5mm | 6.5×6.5 | D1–D4 |
| Crystal 3.2×1.5mm | 5×3 | Y1 |
| Buzzer 12mm | 14×11 | BZ1 |
| NR-40xx Inductor | 5×5 | L3, L4 |
| SW_SPST_TL3342 | 4.5×3.5 | SW1, SW2 |
| LED_0805 | 2.5×1.5 | LED1–3 |
| Molex PicoBlade 3-pin | 6×4 | J2–J9 |
| JST PH 2-pin | 7×5 | J12 |
| Hirose FH12-14S FPC | 12×4 | J10 |
| microSD Molex | 14×16 | J11 |
| 0402 (C/R) | 1.5×0.8 | Most caps/resistors |
| 0805 (C) | 2.5×1.8 | C1,C3,C6,C8,C10,etc. |
| L_0402 | 1.5×0.8 | FB1 |

---

## Zone 1 — MCU Zone (top half, Y = 5–30)

### ESP32-S3 (U1)
| Ref | X | Y | Notes |
|-----|---|---|---|
| **U1** | **25** | **18** | ESP32-S3-WROOM (18×25.5mm body). Antenna faces TOP edge. Keep 5mm above Y=5 for antenna clearance. |

> [!WARNING]
> U1 courtyard extends from X=16 to X=34, Y=5.25 to Y=30.75. Keep ALL other components outside this zone.

### RP2040 + Flash (U2, U3)
| Ref | X | Y | Notes |
|-----|---|---|---|
| **U2** | **65** | **20** | RP2040 QFN-56 (7×7mm body). Center of digital zone. |
| **U3** | **78** | **20** | W25Q128 Flash SOIC-8. 8mm right of U2 center (min clearance: body gap ~4mm). |
| **Y1** | **57** | **17** | 12MHz Crystal. 4mm left of U2 edge. Close enough for signal integrity, far enough for clearance. |

### SWD Debug Header
| Ref | X | Y | Notes |
|-----|---|---|---|
| **J13** | **74** | **12** | Tag-Connect 2050. Below D4, clear of BZ1 and U3. |

### TFT Display Connector
| Ref | X | Y | Notes |
|-----|---|---|---|
| **J10** | **95** | **22** | FPC-14 connector. Right edge of board. |

### Buttons
| Ref | X | Y | Notes |
|-----|---|---|---|
| **SW1** | **6** | **18** | Reset button. Left edge, far from U1. |
| **SW2** | **6** | **24** | Boot button. Below SW1, 6mm gap. |

---

## Zone 2 — Power Zone (left side, Y = 32–60)

### USB-C Connector
| Ref | X | Y | Notes |
|-----|---|---|---|
| **J1** | **1.5** | **44** | USB-C. Sticks out from left edge. Body extends X=0–10, Y=40–48. |

### Charger IC (BQ24075)
| Ref | X | Y | Notes |
|-----|---|---|---|
| **U13** | **18** | **40** | WQFN-24 (4×4mm). Courtyard: X=15–21, Y=37–43. |

### Inductors
| Ref | X | Y | Notes |
|-----|---|---|---|
| **L3** | **18** | **34** | Charger inductor (5×5mm). Above U13, 3mm gap. |
| **L4** | **26** | **34** | Buck-boost inductor (5×5mm). Right of L3, 3mm gap. |

### Buck-Boost (TPS63020)
| Ref | X | Y | Notes |
|-----|---|---|---|
| **U14** | **30** | **40** | TPS63020 (4.5×3.5mm). Right of U13, 4mm gap. |

### LDOs & Power Management
| Ref | X | Y | Notes |
|-----|---|---|---|
| **U16** | **18** | **50** | AMS1117 SOT-223 (7.5×4mm). Below U13, 4mm gap. |
| **U15** | **30** | **50** | TPS7A20 SOT-23-5 (3.5×2mm). Below U14. |
| **FB1** | **26** | **50** | Ferrite bead 0402. Between U16 and U15. |
| **U17** | **12** | **56** | MAX17048 fuel gauge (3×3mm). Below-left. |

### Battery Connector
| Ref | X | Y | Notes |
|-----|---|---|---|
| **J12** | **5** | **56** | JST PH 2-pin (7×5mm). Left edge, near U17. |

---

## Zone 3 — WS2812B LED Strip (top edge, Y = 3–10)

| Ref | X | Y | Notes |
|-----|---|---|---|
| **D1** | **53** | **4** | WS2812B (5×5mm). Start after ESP32 antenna keepout zone ends at X=49. |
| **D2** | **60** | **4** | 7mm spacing (courtyard 6.5mm, so 0.5mm gap). |
| **D3** | **67** | **4** | Continues rightward. |
| **D4** | **74** | **4** | Last LED. Ends before BZ1 courtyard. |

### Buzzer
| Ref | X | Y | Notes |
|-----|---|---|---|
| **BZ1** | **87** | **7** | Buzzer (14×11mm). Top-right, shifted right and down to stay inside PCB. |
| **Q1** | **87** | **16** | Buzzer driver SOT-23. Directly below BZ1. |

---

## Zone 4 — Electrochemical (bottom-center, Y = 58–76)

| Ref | X | Y | Notes |
|-----|---|---|---|
| **U4** | **35** | **65** | AD5941 #1 QFN-49 (7×7mm). Courtyard: X=30.75–39.25, Y=60.75–69.25. |
| **U5** | **60** | **65** | AD5941 #2 QFN-49 (7×7mm). 25mm right of U4. Courtyard: X=55.75–64.25. |

---

## Zone 5 — Sensor Array (right-center, Y = 32–55)

| Ref | X | Y | Notes |
|-----|---|---|---|
| **U7** | **50** | **45** | TCA9548A I2C MUX VQFN-24 (4×4mm). |
| **U8** | **60** | **35** | MAX30102 OLGA-14 (3.3×5.6mm). |
| **U10** | **60** | **48** | DS3231 RTC SOIC-16W (7.5×10.3mm). Keep 6mm from U7. |
| **U9** | **74** | **35** | MLX90614 TO-254 (8×9mm). Large package, needs space. |
| **U11** | **74** | **48** | LSM6DSO PQFN-14 (2.5×3mm). |

---

## Zone 6 — Optical (far right, Y = 35–55)

| Ref | X | Y | Notes |
|-----|---|---|---|
| **U6** | **88** | **48** | AS7341 spectral sensor OLGA-8 (2×3.1mm). |
| **Q3** | **84** | **36** | UV LED MOSFET SOT-23. |
| **Q4** | **88** | **36** | Blue LED MOSFET SOT-23. 4mm right of Q3. |
| **Q5** | **92** | **36** | White LED MOSFET SOT-23. 4mm right of Q4. |
| **LED1** | **84** | **42** | UV indicator LED 0805. Below Q3. |
| **LED2** | **88** | **42** | Blue indicator LED 0805. Below Q4. |
| **LED3** | **92** | **42** | White indicator LED 0805. Below Q5. |

---

## Zone 7 — Thermal (bottom-right, Y = 75–95)

| Ref | X | Y | Notes |
|-----|---|---|---|
| **U12** | **85** | **78** | TMP117 WSON-6 (2×2mm). |
| **Q2** | **80** | **78** | Heater MOSFET SOT-23. |

---

## Zone 8 — Sensor Connectors (bottom edge, Y = 92–96)

| Ref | X | Y | Notes |
|-----|---|---|---|
| **J2** | **16** | **95** | Sensor port 1 |
| **J3** | **24** | **95** | Sensor port 2 (8mm spacing) |
| **J4** | **32** | **95** | Sensor port 3 |
| **J5** | **40** | **95** | Sensor port 4 |
| **J6** | **52** | **95** | Sensor port 5 |
| **J7** | **60** | **95** | Sensor port 6 |
| **J8** | **68** | **95** | Sensor port 7 |
| **J9** | **76** | **95** | Sensor port 8 |

### microSD + Debug
| Ref | X | Y | Notes |
|-----|---|---|---|
| **J11** | **92** | **58** | microSD slot (14×16mm). Right edge. |

---

## Visual Board Map

```
 0        10       20       30       40       50       60       70       80       90      100
 ┌─────────┬────────┬────────┬────────┬────────┬────────┬────────┬────────┬────────┬────────┐
 │         │        │        │        │        │  D1    │D2 D3 D4│        │ BZ1    │        │ 5
 │ SW1     │        │        │        │        │        │  J13   │        │        │        │ 10
 │         │        │ U1     │        │        │        │ Y1  U2 │   U3   │        │ J10    │ 20
 │ SW2     │        │(ESP32) │        │        │        │        │        │        │        │ 25
 │         │        │        │ L3  L4 │        │        │        │        │        │        │ 35
 │ J1      │   U13  │   U14  │        │        │ U7     │ U8     │ U9     │ Q3 Q4 Q5       │ 40
 │(USB-C)  │        │        │        │        │        │        │        │LED1,2,3│        │ 45
 │         │   U16  │FB U15  │        │        │   U10  │        │ U11    │   U6   │        │ 50
 │ J12 U17 │        │        │        │        │        │        │        │        │  J11   │ 55
 │         │        │        │   U4   │        │        │   U5   │        │        │        │ 65
 │         │        │        │(AD5941)│        │        │(AD5941)│        │        │        │ 70
 │         │        │        │        │        │        │        │  Q2 U12│        │        │ 78
 │         │        │        │        │        │        │        │        │        │        │ 85
 │   J2    │  J3    │  J4    │  J5    │  J6    │  J7    │  J8    │  J9    │        │        │ 95
 └─────────┴────────┴────────┴────────┴────────┴────────┴────────┴────────┴────────┴────────┘
```

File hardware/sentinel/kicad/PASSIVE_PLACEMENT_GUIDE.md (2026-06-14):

# Passive Component Placement Guide — Capacitors, Resistors & Small Parts

All coordinates in mm. Place each component: **Click → Press E → type X, Y**.

> [!IMPORTANT]
> Place ALL **main ICs first** using the [Component Placement Guide](file:///C:/Users/dhruv/CARVanta/hardware/sentinel/kicad/COMPONENT_PLACEMENT_GUIDE.md), then use this file to place passives.

> [!TIP]
> **Minimum spacing rules used in this guide:**
> - 0402 to 0402: **1.5mm** center-to-center minimum (courtyard 1.5×0.8mm)
> - 0805 to 0805: **3mm** center-to-center minimum (courtyard 2.5×1.8mm)
> - 0402 to IC edge: **1.5mm** from IC courtyard boundary
> - 0805 to IC edge: **2mm** from IC courtyard boundary
>
> All coordinates below respect these minimums.

---

## Power Section — USB Area

### Near J1 (USB-C at 1.5, 44) — courtyard X=0–10, Y=40–48

| Ref | Value | Size | X | Y | Belongs To |
|-----|---|---|---|---|---|
| R1 | 5.1kΩ | 0402 | 12 | 42 | J1 CC1 pulldown |
| R2 | 5.1kΩ | 0402 | 12 | 46 | J1 CC2 pulldown |
| C2 | 1µF | 0402 | 12 | 44 | J1 VBUS bypass |
| C21 | 10µF | 0805 | 12 | 40 | VBUS bulk cap |

> [!NOTE]
> R1/R2 are placed 2mm right of J1 courtyard edge (X=10). Vertical spacing is 2mm.

---

## Power Section — BQ24075 Charger Area

### Near U13 (18, 40) — courtyard X=15–21, Y=37–43

| Ref | Value | Size | X | Y | Belongs To |
|-----|---|---|---|---|---|
| C1 | 10µF | 0805 | 13 | 38 | U13 VBUS input cap |
| C4 | 1µF | 0402 | 23 | 38 | U13 REGN cap |
| C5 | 100nF | 0402 | 15 | 34 | U13 BTST cap (near L3) |
| R3 | 10kΩ | 0402 | 23 | 42 | U13 CE pulldown |
| R4 | 10kΩ | 0402 | 13 | 44 | U13 OTG pulldown |
| R5 | 10kΩ | 0402 | 13 | 36 | U13 QON pullup |

> [!NOTE]
> C1 (0805) is placed 2mm left of U13 courtyard. C4 is 2mm right. R3/R4 are below U13.

---

## Power Section — TPS63020 Buck-Boost Area

### Near U14 (30, 40) — courtyard X=27.75–32.25, Y=38.25–41.75

| Ref | Value | Size | X | Y | Belongs To |
|-----|---|---|---|---|---|
| C3 | 10µF | 0805 | 26 | 43 | U14 VIN cap (input side) |
| C6 | 22µF | 0805 | 34 | 38 | U14 VOUT cap |
| C7 | 100nF | 0402 | 34 | 40 | U14 VOUT bypass |
| C8 | 22µF | 0805 | 34 | 43 | U14 output bulk cap |
| C9 | 100nF | 0402 | 26 | 38 | U14 VIN bypass |
| R3 | 10kΩ | 0402 | 34 | 45 | FB top divider |
| R4 | 10kΩ | 0402 | 36 | 45 | FB bottom divider |

---

## Power Section — TLV733 / AMS1117 LDO Area

### Near U16 (18, 50) — courtyard X=14.25–21.75, Y=48–52

| Ref | Value | Size | X | Y | Belongs To |
|-----|---|---|---|---|---|
| C10 | 10µF | 0805 | 12 | 50 | U16 input cap |
| C11 | 100nF | 0402 | 12 | 48 | U16 input bypass |
| C12 | 10µF | 0805 | 24 | 50 | U16 output cap (3V3_D) |
| C20 | 22µF | 0805 | 24 | 53 | U16 output bulk cap |

### Near U15 (30, 50) — courtyard X=28.25–31.75, Y=49–51

| Ref | Value | Size | X | Y | Belongs To |
|-----|---|---|---|---|---|
| C16 | 1µF | 0402 | 28 | 53 | U15 input cap |
| C17 | 1µF | 0402 | 32 | 53 | U15 output cap |

### Extra Power Caps

| Ref | Value | Size | X | Y | Belongs To |
|-----|---|---|---|---|---|
| C18 | 100nF | 0402 | 32 | 48 | Power rail bypass |
| C19 | 10µF | 0805 | 28 | 48 | Power rail bypass |

---

## Power Section — MAX17048 Fuel Gauge Area

### Near U17 (12, 56) — courtyard X=10.5–13.5, Y=54.5–57.5

| Ref | Value | Size | X | Y | Belongs To |
|-----|---|---|---|---|---|
| C13 | 100nF | 0402 | 9 | 54 | U17 VDD bypass |
| C14 | 10µF | 0805 | 9 | 58 | Battery bypass |
| C15 | 100nF | 0402 | 9 | 60 | Battery bypass |
| R6 | 10kΩ | 0402 | 15 | 58 | U17 QSTRT pullup |

---

## ESP32 Section

### Near U1 (25, 18) — courtyard X=16–34, Y=5.25–30.75

> [!WARNING]
> U1 is the LARGEST component (18×25.5mm courtyard). Passives must go OUTSIDE X=16–34, Y=5.25–30.75.

| Ref | Value | Size | X | Y | Belongs To |
|-----|---|---|---|---|---|
| C22 | 100nF | 0402 | 14 | 14 | U1 3V3 bypass 1 (near Pin 1) |
| C23 | 100nF | 0402 | 14 | 16 | U1 3V3 bypass 2 |
| C24 | 100nF | 0402 | 36 | 14 | U1 3V3 bypass 3 |
| C25 | 100nF | 0402 | 14 | 18 | U1 EN bypass (near Pin 3) |
| C26 | 100nF | 0402 | 36 | 17 | U1 3V3 bypass 4 |
| C27 | 22µF | 0805 | 36 | 21 | U1 bulk bypass |
| R7 | 10kΩ | 0402 | 4 | 16 | U1 EN pullup (near SW1) |
| R8 | 10kΩ | 0402 | 4 | 22 | U1 GPIO0 pullup (near SW2) |

> [!NOTE]
> Caps are split: C22, C23, C25 are on the left (X=14) and C24, C26, C27 are on the right (X=36), all placed below Y=13 to remain completely outside the ESP32 footprint's built-in antenna keepout zone. R7/R8 at X=4 (left of SW1/SW2).

---

## RP2040 Section

### Near U2 (65, 20) — courtyard X=60.75–69.25, Y=15.75–24.25

| Ref | Value | Size | X | Y | Belongs To |
|-----|---|---|---|---|---|
| C28 | 100nF | 0402 | 59 | 14 | U2 IOVDD bypass |
| C29 | 100nF | 0402 | 59 | 26 | U2 VREG_VIN bypass |
| C30 | 1µF | 0402 | 71 | 14 | U2 VREG_VOUT/DVDD cap |
| C31 | 1µF | 0402 | 71 | 26 | U2 DVDD cap |
| C34 | 15pF | 0402 | 55 | 15 | Y1 crystal load cap 1 |
| C35 | 15pF | 0402 | 55 | 19 | Y1 crystal load cap 2 |
| R9 | 10kΩ | 0402 | 59 | 26 | U2 RUN pullup |

> [!NOTE]
> C28–C31 are placed 1.5mm outside U2 courtyard edges. C34/C35 flanking Y1 at X=55.

### Near U3 (78, 20) — courtyard X=74.9–81.1, Y=17.4–22.6

| Ref | Value | Size | X | Y | Belongs To |
|-----|---|---|---|---|---|
| C32 | 100nF | 0402 | 73 | 16 | U2 USB_VDD bypass |
| C33 | 100nF | 0402 | 73 | 24 | U2 ADC_AVDD bypass |
| C36 | 100nF | 0402 | 82 | 18 | U3 Flash VCC bypass |
| R10 | 10kΩ | 0402 | 82 | 20 | U3 WP pullup |
| R11 | 10kΩ | 0402 | 82 | 22 | U3 HOLD pullup |
| R12 | 10kΩ | 0402 | 73 | 20 | U2 spare pullup |

> [!NOTE]
> C32/C33 at X=73 (left of U3). C36/R10/R11 at X=82 (right of U3). All clear of J13 at (85, 10).

---

## Electrochemical Section

### Near U4 (35, 65) — courtyard X=30.75–39.25, Y=60.75–69.25

| Ref | Value | Size | X | Y | Belongs To |
|-----|---|---|---|---|---|
| C37 | 100nF | 0402 | 29 | 59 | U4 AVDD1 bypass |
| C38 | 10nF | 0402 | 29 | 71 | U4 AVDD1 small cap |
| C39 | 100nF | 0402 | 41 | 59 | U4 AVDD2 bypass |
| C40 | 100nF | 0402 | 41 | 71 | U4 DVDD bypass |
| C41 | 1µF | 0402 | 29 | 61 | U4 VREF_2V5 cap |
| C42 | 1µF | 0402 | 41 | 61 | U4 VREF_1V82 cap |
| C43 | 1µF | 0402 | 29 | 69 | U4 VBIAS cap |
| C44 | 1µF | 0402 | 41 | 69 | U4 DVDD_REG cap |
| R13 | 10kΩ | 0402 | 35 | 73 | U4 RCAL precision |

> [!NOTE]
> Passives placed in a ring 1.5mm outside U4's courtyard. 2mm clear of each other.

### Near U5 (60, 65) — courtyard X=55.75–64.25, Y=60.75–69.25

| Ref | Value | Size | X | Y | Belongs To |
|-----|---|---|---|---|---|
| C45 | 100nF | 0402 | 54 | 59 | U5 AVDD1 bypass |
| C46 | 10nF | 0402 | 54 | 71 | U5 AVDD1 small cap |
| C47 | 100nF | 0402 | 66 | 59 | U5 AVDD2 bypass |
| C48 | 1µF | 0402 | 54 | 61 | U5 VREF_2V5 cap |
| C49 | 100nF | 0402 | 66 | 71 | U5 DVDD bypass |
| C50 | 1µF | 0402 | 66 | 61 | U5 VREF_1V82 cap |
| C51 | 1µF | 0402 | 54 | 69 | U5 VBIAS cap |
| C52 | 1µF | 0402 | 66 | 69 | U5 DVDD_REG cap |
| R14 | 10kΩ | 0402 | 60 | 73 | U5 RCAL precision |

---

## Optical Section

### Near U6 (88, 48) — courtyard X=86.25–89.75, Y=45.95–50.05

| Ref | Value | Size | X | Y | Belongs To |
|-----|---|---|---|---|---|
| C53 | 100nF | 0402 | 91 | 48 | U6 VDD bypass |

### LED Driver Resistors — near Q3–Q5 and LED1–3

| Ref | Value | Size | X | Y | Belongs To |
|-----|---|---|---|---|---|
| R15 | 100Ω | 0402 | 84 | 34 | Q3 gate resistor (UV) |
| R16 | 100Ω | 0402 | 88 | 34 | Q4 gate resistor (Blue) |
| R17 | 100Ω | 0402 | 92 | 34 | Q5 gate resistor (White) |
| R18 | 68Ω | 0402 | 84 | 44 | LED1 current limit |
| R19 | 47Ω | 0402 | 88 | 44 | LED2 current limit |
| R20 | 100Ω | 0402 | 92 | 44 | LED3 current limit |

> [!NOTE]
> R15–R17 are 2mm above Q3–Q5. R18–R20 are 2mm below LED1–3. Aligned to same X as their MOSFETs/LEDs.

---

## Thermal Section

### Near Q2 (80, 78) and U12 (85, 78)

| Ref | Value | Size | X | Y | Belongs To |
|-----|---|---|---|---|---|
| R21 | 100Ω | 0402 | 78 | 76 | Q2 gate resistor |
| R22 | 10kΩ | 0402 | 82 | 76 | Q2 gate pulldown |
| C59 | 100nF | 0402 | 87 | 76 | U12 VDD bypass |

---

## Sensors & Display Section

### Sensor IC Bypass Caps

| Ref | Value | Size | X | Y | Belongs To | Near IC |
|-----|---|---|---|---|---|---|
| C54 | 100nF | 0402 | 48 | 43 | U7 VCC bypass | U7 (50,45) |
| C55 | 100nF | 0402 | 58 | 33 | U8 VDD bypass | U8 (60,35) |
| C56 | 100nF | 0402 | 72 | 33 | U9 VDD bypass | U9 (74,35) |
| C57 | 100nF | 0402 | 58 | 50 | U10 VCC bypass | U10 (60,48) |
| C58 | 100nF | 0402 | 72 | 50 | U11 VDD bypass | U11 (74,48) |

> [!NOTE]
> Each bypass cap is placed 2mm left of its parent IC, at the same Y or 2mm above. All are well separated.

### WS2812B LED Bypass Caps — near D1–D4

| Ref | Value | Size | X | Y | Belongs To |
|-----|---|---|---|---|---|
| C60 | 100nF | 0402 | 53 | 9 | D1 bypass (D1 at 53, 4) |
| C61 | 100nF | 0402 | 60 | 9 | D2 bypass (D2 at 60, 4) |
| C62 | 100nF | 0402 | 67 | 9 | D3 bypass (D3 at 67, 4) |
| C63 | 100nF | 0402 | 74 | 9 | D4 bypass (D4 at 74, 4) |

> [!NOTE]
> Caps placed 5mm below LED center (Y=4+5=9). Same X as parent LED. WS2812B courtyard extends ±3.25mm, so Y=9 is clear of courtyard Y=0.75–7.25.

### Buzzer MOSFET Resistor

| Ref | Value | Size | X | Y | Belongs To |
|-----|---|---|---|---|---|
| R24 | 100Ω | 0402 | 82 | 16 | Q1 gate resistor (Q1 at 87, 16) |

---

## Quick Reference — All Passives Sorted by Ref

| Ref | X | Y | | Ref | X | Y | | Ref | X | Y |
|-----|---|---|-|-----|---|---|-|-----|---|---|
| C1 | 13 | 38 | | C22 | 14 | 14 | | C43 | 29 | 69 |
| C2 | 12 | 44 | | C23 | 14 | 16 | | C44 | 41 | 69 |
| C3 | 26 | 43 | | C24 | 36 | 14 | | C45 | 54 | 59 |
| C4 | 23 | 38 | | C25 | 14 | 18 | | C46 | 54 | 71 |
| C5 | 15 | 34 | | C26 | 36 | 17 | | C47 | 66 | 59 |
| C6 | 34 | 38 | | C27 | 36 | 21 | | C48 | 54 | 61 |
| C7 | 34 | 40 | | C28 | 59 | 14 | | C49 | 66 | 71 |
| C8 | 34 | 43 | | C29 | 59 | 26 | | C50 | 66 | 61 |
| C9 | 26 | 38 | | C30 | 71 | 14 | | C51 | 54 | 69 |
| C10 | 12 | 50 | | C31 | 71 | 26 | | C52 | 66 | 69 |
| C11 | 12 | 48 | | C32 | 73 | 16 | | C53 | 91 | 48 |
| C12 | 24 | 50 | | C33 | 73 | 24 | | C54 | 48 | 43 |
| C13 | 9 | 54 | | C34 | 55 | 15 | | C55 | 58 | 33 |
| C14 | 9 | 58 | | C35 | 55 | 19 | | C56 | 72 | 33 |
| C15 | 9 | 60 | | C36 | 82 | 18 | | C57 | 58 | 50 |
| C16 | 28 | 53 | | C37 | 29 | 59 | | C58 | 72 | 50 |
| C17 | 32 | 53 | | C38 | 29 | 71 | | C59 | 87 | 76 |
| C18 | 32 | 48 | | C39 | 41 | 59 | | C60 | 53 | 9 |
| C19 | 28 | 48 | | C40 | 41 | 71 | | C61 | 60 | 9 |
| C20 | 24 | 53 | | C41 | 29 | 61 | | C62 | 67 | 9 |
| C21 | 12 | 40 | | C42 | 41 | 61 | | C63 | 74 | 9 |

| Ref | X | Y | | Ref | X | Y |
|-----|---|---|-|-----|---|---|
| R1 | 12 | 42 | | R13 | 35 | 73 |
| R2 | 12 | 46 | | R14 | 60 | 73 |
| R3 | 34 | 45 | | R15 | 84 | 34 |
| R4 | 36 | 45 | | R16 | 88 | 34 |
| R5 | 13 | 36 | | R17 | 92 | 34 |
| R6 | 15 | 58 | | R18 | 84 | 44 |
| R7 | 4 | 16 | | R19 | 88 | 44 |
| R8 | 4 | 22 | | R20 | 92 | 44 |
| R9 | 59 | 26 | | R21 | 78 | 76 |
| R10 | 82 | 20 | | R22 | 82 | 76 |
| R11 | 82 | 22 | | R24 | 82 | 16 |
| R12 | 73 | 20 | | FB1 | 26 | 50 |

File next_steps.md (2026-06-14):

# CARVanta — The Real Roadmap

> **Goal:** Transform CARVanta from a 100K-line proof-of-concept into a validated immunotherapy intelligence tool that a researcher would actually use.

> [!CAUTION]
> This document is brutally honest. It identifies what's real, what's fake, and what needs to happen — in order — to make CARVanta competitive.

---

## Part 1: Honest Assessment — What We Have vs What We Claim

### What's real (keep)
| Component | Why it's real |
|---|---|
| **Architecture** | 11 modular subsystems, clean API layer, React frontend — genuinely well-engineered |
| **CVS Scoring Formula** | Weighted multi-factor approach (specificity, safety, stability, evidence, immunogenicity) is scientifically sound in concept |
| **ML Pipeline** | RF + XGBoost ensemble trained on features — the pipeline works, just needs real training data |
| **NLP Query Engine** | Natural language antigen search — unique feature, works today |
| **Frontend UX** | 45 pages, functional UI — better than most academic tools |
| **API Design** | 451 routes, versioned, documented — production-grade structure |

### What's fake (must fix)
| Component | The problem |
|---|---|
| **Expression data** | `generate_features()` uses `hash(antigen_name)` and `random.uniform()` to create fake tumor specificity, safety margins, etc. A researcher would spot this instantly |
| **Multi-omics engines** | `omics/transcriptomics.py` through `single_cell.py` generate plausible-looking data structures but contain zero real biological data |
| **Digital twin ODEs** | The differential equations look right but aren't parameterized from real clinical data. No validation against actual patient outcomes |
| **Clinical trials data** | `clinical_trials_endpoint()` generates fake NCT numbers and randomized phase distributions instead of calling the real ClinicalTrials.gov API |
| **Drug interactions** | Hardcoded list of ~20 interactions. Real tools use DrugBank (13K+ interactions) |
| **Safety profiles** | Normal tissue expression is randomly generated. Should come from GTEx (real tissue-specific expression) |
| **Neoantigen prediction** | `genomics/neoantigen_predictor.py` simulates MHC binding. Real tools use NetMHCpan or MHCflurry |
| **Literature/PubMed** | `collab/pubmed_linker.py` likely generates fake citations. PubMed has a free E-utilities API |
| **Patent data** | Generated, not from real patent databases |
| **SHAP explanations** | May use approximate/fake SHAP values instead of actual model explanations |

### What doesn't matter (cut or deprioritize)
| Component | Why |
|---|-----|
| **Line count targets** | Nobody cares about 127K lines. A 20K-line tool with real data beats a 200K-line tool with fake data |
| **Health Economics module** | Nice-to-have. No researcher picks a tool because it has QALY calculators |
| **Collaboration Hub (22 engines)** | Massively over-engineered. Real collaboration = share a link. You don't need 22 sub-engines |
| **Voice handler** | Nobody uses voice in a lab with a biosafety cabinet running |
| **Multi-tenant architecture** | Premature. Get 1 user before worrying about 1000 |
| **Billing/Stripe integration** | Way premature. The tool isn't validated yet |
| **i18n / 20 languages** | Premature. English-only is fine for v1 |

---

## Part 2: The Four Phases

### Phase 1: Real Data Foundation (Weeks 1-4)

**The single most important thing.** Every number in CARVanta must trace back to a real data source.

#### 1.1 — TCGA Gene Expression (Week 1)

**What:** Download preprocessed TCGA pan-cancer expression data and use it as CARVanta's truth layer.

**Source:** [UCSC Xena Browser](https://xenabrowser.net/datapages/) — free, no login required
- File: `TCGA-PANCAN/HiSeqV2.gz` (~800MB) — gene expression for 11,060 samples across 33 cancer types
- Format: TSV, genes × samples matrix

**How:**
```
data/
  tcga_expression.tsv.gz    ← download once, ship with repo (or download on first run)
  gtex_expression.tsv.gz
  antigen_metadata.json     ← curated list of known CAR-T targets with ground truth labels
```

**What changes in code:**
- `scoring/feature_generator.py` (or wherever `generate_features()` lives) stops using `hash()` and starts querying the real expression matrix
- `tumor_specificity` = median expression in tumor samples / median in normal samples (real ratio)
- `normal_expression_risk` = max expression across GTEx normal tissues (real safety signal)
- `stability_score` = coefficient of variation across tumor samples (real consistency measure)

**Validation:** After this step, when someone scores CD19:
- Tumor expression comes from real TCGA DLBCL samples
- Normal expression comes from real GTEx tissues
- The score MEANS something

#### 1.2 — GTEx Normal Tissue Expression (Week 1)

**What:** Download GTEx median expression per tissue type. This is what makes safety scoring real.

**Source:** [GTEx Portal](https://gtexportal.org/home/downloads/adult-gtex/bulk_tissue_expression) — free with registration
- File: `GTEx_Analysis_2017-06-05_v8_RNASeQCv1.1.9_gene_median_tpm.gct.gz`
- Contains median TPM for every gene across 54 human tissues

**What changes:**
- `features/safety.py` uses real tissue expression to flag dangerous targets
- If CD19 has high expression in heart tissue (it doesn't, but if it did), the safety score drops
- This replaces ALL the `random.uniform()` calls in safety assessment

#### 1.3 — ClinicalTrials.gov Live API (Week 2)

**What:** Replace the fake trial generator with real API calls.

**API:** `https://clinicaltrials.gov/api/v2/studies`
**Cost:** Free, no API key needed
**Rate limit:** 100 requests/minute (generous)

**What changes:**
- `trials/clinicaltrials_sync.py` makes real HTTP requests
- `clinical_trials_endpoint()` returns real NCT IDs, real trial titles, real phase distributions
- Cache results in SQLite (already have the DB layer) to avoid hitting the API on every request

**Example query:**
```
GET https://clinicaltrials.gov/api/v2/studies?query.term=CAR-T+CD19&pageSize=50
```

Returns real trials with real NCT numbers. This is the easiest win — the API is free, well-documented, and returns JSON.

#### 1.4 — UniProt Protein Data (Week 2)

**What:** For each antigen, pull real protein data: subcellular location, molecular function, tissue specificity.

**API:** `https://rest.uniprot.org/uniprotkb/search?query=gene:CD19+AND+organism_id:9606`
**Cost:** Free, no key

**What changes:**
- `discovery/proteome_scanner.py` queries real protein metadata
- `surface_accessibility` comes from actual UniProt subcellular location annotations
- `immunogenicity_score` can be informed by protein length, glycosylation sites, etc.

#### 1.5 — Curated Ground Truth Dataset (Week 3)

**What:** Create a hand-curated JSON file of ~50 well-characterized CAR-T targets with known clinical outcomes.

```json
{
  "CD19": {
    "fda_approved": true,
    "approved_products": ["Kymriah", "Yescarta", "Tecartus", "Breyanzi"],
    "best_indication": "B-ALL, DLBCL",
    "overall_response_rate": 0.83,
    "complete_response_rate": 0.54,
    "grade3_crs_rate": 0.23,
    "known_limitations": ["antigen loss", "lineage switch"],
    "clinical_evidence_level": "Phase III",
    "references": ["PMID:29385376", "PMID:28983556"]
  },
  "BCMA": {
    "fda_approved": true,
    "approved_products": ["Abecma", "Carvykti"]
  }
}
```

**This is the most important file in the entire project.** It's what you validate against. Every claim CARVanta makes must be testable against this ground truth.

Sources for this data:
- FDA approval letters (public)
- Published Phase III trial results (PubMed — free)
- ASCO/ASH conference abstracts (public)

#### 1.6 — Retrain ML Models on Real Data (Week 4)

**What:** Once you have real TCGA/GTEx expression data:
1. Generate real features for all ~500 antigens in your database
2. Label them using the curated ground truth (FDA-approved = viable, failed Phase III = not viable)
3. Retrain RF + XGBoost on real features with real labels
4. Cross-validate properly (leave-one-out for the small validated set)

**After Phase 1, CARVanta's numbers mean something.** Every score traces to TCGA, GTEx, UniProt, or ClinicalTrials.gov. That's the foundation.

---

### Phase 2: Scientific Validation (Weeks 5-8)

#### 2.1 — Benchmark Against FDA-Approved Targets

There are currently **6 FDA-approved CAR-T products** targeting **2 antigens** (CD19 and BCMA), plus ~15 targets in late-stage clinical trials:

| Antigen | Status | Expected CARVanta ranking |
|---|---|---|
| CD19 | FDA-approved (4 products) | Should be top 5% |
| BCMA | FDA-approved (2 products) | Should be top 5% |
| CD22 | Phase II | Should be top 15% |
| HER2 | Phase I/II (solid tumors) | Should be top 20% |
| GD2 | Phase I/II (neuroblastoma) | Should be top 20% |
| EGFR | Phase I (glioblastoma) | Should be top 25% |
| Claudin18.2 | Phase I/II (gastric) | Should be top 25% |
| GPRC5D | Phase I/II (myeloma) | Should rank near BCMA |
| FLT3 | Phase I (AML) | Should be top 30% |

**The test:** Run CARVanta's scoring on ALL antigens in the database. Do the FDA-approved ones come out on top? If CD19 scores 0.948 and some random gene scores 0.96, something is wrong.

**Metric:** Spearman rank correlation between CARVanta CVS score and clinical stage (FDA-approved > Phase III > Phase II > Phase I > Preclinical > No trials).

**Target:** ρ ≥ 0.75 would be publishable. ρ ≥ 0.85 would be impressive.

#### 2.2 — Validate Safety Predictions

Using GTEx normal tissue expression:
- Targets with high normal tissue expression SHOULD get lower safety scores
- CD19's known on-target/off-tumor toxicity (B-cell aplasia) should be reflected in the safety module
- Compare your safety rankings against published toxicity reviews (several exist in Nature Reviews Cancer)

#### 2.3 — Cross-Cancer Validation

Your platform scores antigens per cancer type. Test:
- Does CD19 score highest in B-cell malignancies (where it's actually used)?
- Does HER2 score highest in breast/gastric cancer?
- Does PSMA score highest in prostate cancer?

If the cancer-type contextual scoring works correctly with real data, that's a unique feature.

#### 2.4 — Failure Case Analysis

**Equally important:** identify what CARVanta gets WRONG and document it honestly.
- Does it rank any dangerous target too high?
- Does it miss any good target?
- What are the failure modes?

Honest failure analysis is what separates science from marketing.

---

### Phase 3: Scientific Credibility (Weeks 9-12)

#### 3.1 — Write a Preprint

**Title suggestion:** *"CARVanta: An Open-Source AI Platform for Multi-Factor Evaluation of CAR-T Cell Therapy Antigen Targets"*

**Structure:**
1. **Introduction** — The antigen selection bottleneck in CAR-T development
2. **Methods** — CVS scoring algorithm, data sources (TCGA, GTEx, UniProt), ML ensemble
3. **Results** — Benchmark against FDA-approved targets, cross-cancer validation
4. **Discussion** — Limitations, failure cases, future directions
5. **Availability** — Open source, GitHub link

**Where to publish:**
- **bioRxiv** (preprint, instant, free) — gets you visibility immediately
- **Bioinformatics** (Oxford, peer-reviewed) — respected in computational biology
- **JITC** (Journal of Immunotherapy of Cancer) — if clinical validation is strong
- **NAR Webserver issue** (Nucleic Acids Research) — specifically for tools/platforms

#### 3.2 — Open Source Properly

Your GitHub repo needs:
- Clear README with installation instructions that actually work
- `pip install carvanta` or at minimum `docker compose up`
- Example notebooks showing real analyses
- Contributing guide
- License (already have — good)
- CI/CD with tests that pass

#### 3.3 — Get Real Users

1. **Post on Twitter/X** — tag computational immunology researchers
2. **Post on Reddit** — r/bioinformatics, r/immunology
3. **Post on Hacker News** — "Show HN: Open-source AI platform for CAR-T target evaluation"
4. **Submit to bio.tools** — the registry of bioinformatics tools
5. **Email 5 immunology PhD students** — offer to run their antigens through CARVanta for free

One real user's feedback > 10,000 lines of code.

#### 3.4 — Conference Presentation

- **AACR** (American Association for Cancer Research) — poster abstract
- **ASH** (American Society of Hematology) — relevant for CAR-T
- **ISMB/ECCB** — computational biology audience

Even a poster at a regional conference gives CARVanta scientific legitimacy.

---

### Phase 4: Product Hardening (Weeks 13-16)

Only after Phases 1-3. Code that serves real data to real users.

#### 4.1 — Fix What Matters

| Priority | Task | Why |
|---|---|-----|
| P0 | Make ALL frontend pages work correctly with real backend data | Broken pages = zero credibility |
| P0 | Make `start.bat` reliably start the entire stack | If it doesn't start in 1 command, nobody uses it |
| P1 | Add proper error handling (no blank pages, no "Query failed") | User trust |
| P1 | Cache expensive computations (TCGA queries, ML scoring) | Performance |
| P2 | Add loading states and progress indicators everywhere | UX polish |
| P2 | Mobile-responsive layout | Accessibility |

#### 4.2 — Cut What Doesn't Matter

**Be ruthless.** These add lines but not value:

| Cut/Deprioritize | Reason |
|---|---|
| 22-engine Collaboration Hub | Reduce to: projects, experiments, peer review. Cut the rest |
| Voice handler | Nobody uses this |
| Health Economics (QALY, budget impact) | Nice-to-have, not core |
| Multi-tenant architecture | Premature |
| Billing/Stripe | Premature |
| i18n / language support | Premature |
| Manufacturing simulator | Not core to antigen selection |

#### 4.3 — Deployment

| Option | Cost | Difficulty | Best for |
|---|---|---|---|
| **Railway.app** | $5/mo | Easy | Full stack with DB |
| **Render** | Free tier | Medium | Backend API |
| **Fly.io** | Free tier | Medium | Docker deployment |

---

## Part 3: Priority Stack — What To Do Monday Morning

### This week
1. Download TCGA pan-cancer expression matrix from UCSC Xena
2. Download GTEx median tissue expression
3. Build `data/ground_truth.json` with 50 curated CAR-T targets
4. Replace `generate_features()` with real TCGA/GTEx lookups

### Next week
5. Retrain ML models on real features
6. Run validation benchmark (do FDA-approved targets rank highest?)
7. Connect to ClinicalTrials.gov API for live trial data

### Week after
8. Fix all broken frontend pages
9. Write benchmark results into a document
10. Start drafting the preprint

---

## Part 4: The Competitive Landscape

| Tool | What it does | CARVanta's advantage |
|---|---|---|
| **cBioPortal** | Cancer genomics browser | They show data. You SCORE and RANK targets |
| **CIViC** | Clinical variant interpretation | Manually curated, slow. You're automated |
| **OncoKB** | Precision oncology knowledge base | Drug-focused, not CAR-T specific |
| **IEDB** | Immune epitope database | Epitopes, not CAR-T target selection |
| **Internal pharma tools** | Proprietary, closed | You're open source. That matters |

**CARVanta's unique position:** No open-source tool specifically ranks antigens for CAR-T therapy potential using multi-factor scoring. cBioPortal shows you expression data. CIViC tells you about variants. Neither says "CD19 is your best target for B-ALL, and here's why, scored against 500 alternatives." **That's your moat.**

---

## Part 5: What Success Looks Like

### 3 months from now
- CARVanta scores based on real TCGA/GTEx data
- Benchmark published: correctly ranks FDA-approved targets
- Preprint on bioRxiv
- 5-10 users who aren't you

### 6 months from now
- Peer-reviewed publication
- 100+ GitHub stars
- 1 collaboration with an academic lab

### 12 months from now
- Used by researchers at 3+ institutions
- Cited in at least 1 other paper
- Conference presentation
- Either: seed funding conversation OR lab partnership OR acquisition interest

---

> [!IMPORTANT]
> **The bottom line:** CARVanta's engineering is already competitive. What's missing is truth — real data, real validation, real users. The data is free, the validation is doable, and the users are out there.
>
> 100K lines of synthetic code = impressive project.
> 20K lines of validated code = real tool.
> You have the 100K. Now make 20K of it real.

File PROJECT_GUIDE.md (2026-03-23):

# CARVanta — Project Guide & Website Walkthrough
### *Your Complete Guide to Understanding AI-Powered CAR-T Target Discovery*

---

## What Is CARVanta?

**CARVanta** is an AI-powered platform that helps scientists find the best targets for a cutting-edge cancer treatment called **CAR-T cell therapy**.

### Wait — What Is CAR-T Therapy?

Imagine you could teach your own immune cells to hunt down and kill cancer. That's exactly what CAR-T therapy does:

1. **Doctors take immune cells** (T-cells) from a patient's blood
2. **Engineers modify them** in a lab to recognize a specific protein on cancer cells (called an **antigen**)
3. **The modified T-cells** are put back into the patient, where they seek out and destroy cancer

The big challenge? **Picking the RIGHT target (antigen)**. If you pick the wrong one:
- The T-cells might attack healthy organs (dangerous side effects)
- The cancer might not express enough of the target (treatment fails)
- The target might be unstable (cancer escapes)

**CARVanta solves this problem** using data science and machine learning to score and rank thousands of potential targets — saving researchers months of manual analysis.

---

## How It Works (The Engine Under the Hood)

CARVanta uses a **multi-layer scoring system** to evaluate each antigen:

```
┌──────────────────────────────────────────┐
│          CARVanta v4 Scoring             │
├──────────────────────────────────────────┤
│                                          │
│  Layer 1: Rule-Based CVS Score           │
│  ├─ Tumor Specificity (30%)              │
│  ├─ Safety / Normal Tissue Risk (25%)    │
│  ├─ Protein Stability (15%)              │
│  ├─ Published Research Evidence (10%)    │
│  ├─ Immunogenicity (10%)                 │
│  └─ Surface Accessibility (10%)          │
│                                          │
│  Layer 2: ML Regression Ranker           │
│  ├─ XGBoost model trained on 120K+       │
│  │   biomarker records                   │
│  └─ Predicts "Clinical Success Prob."    │
│                                          │
│  Layer 3: Adaptive Blend                 │
│  └─ 60% CVS + 40% ML = Final Score      │
│                                          │
│  Layer 4: Cancer-Context Awareness       │
│  └─ Scores change per cancer type        │
│     (CD19 scores differently for         │
│      Leukemia vs. Melanoma)              │
│                                          │
└──────────────────────────────────────────┘
```

### The Tier System

Every antigen gets sorted into one of four tiers:

| Tier | Score Range | What It Means |
|---|---|---|
| 🟢 **Tier 1** — Highly Viable | ≥ 0.85 | Ready for clinical trials. Strong evidence, safe, specific to tumors |
| 🔵 **Tier 2** — Promising | 0.70 – 0.84 | Good candidate. Some concerns but worth investigating further |
| 🟡 **Tier 3** — Experimental | 0.55 – 0.69 | Needs more research. Moderate specificity or safety concerns |
| 🔴 **Tier 4** — High Risk | < 0.55 | Not recommended. Poor specificity, high toxicity risk, weak evidence |

---

## The Data Behind It

CARVanta is powered by a database of **120,000+ biomarker records** covering:

- **16,000 unique antigens** (potential targets)
- **18 cancer types** (Leukemia, Breast Cancer, Melanoma, Glioblastoma, etc.)
- **Expression data** showing how much each protein appears on tumor cells vs. healthy cells
- **Safety metrics** — does this target also appear on your heart, brain, or lungs?
- **Clinical trial counts** — has this target already been tested in real patients?

Key antigens you'll see often (these are the stars of CAR-T research):

| Antigen | Primary Cancer | Status |
|---|---|---|
| **CD19** | Leukemia / Lymphoma | ✅ FDA-approved CAR-T products |
| **BCMA** | Multiple Myeloma | ✅ FDA-approved |
| **HER2** | Breast / Gastric Cancer | 🔬 Clinical trials |
| **GD2** | Neuroblastoma | 🔬 Clinical trials |
| **EGFR** | Lung Cancer / Glioblastoma | 🔬 Clinical trials |
| **MSLN** | Mesothelioma / Pancreatic | 🔬 Clinical trials |
| **PSMA** | Prostate Cancer | 🔬 Clinical trials |

---

## Website Walkthrough — Every Page Explained

When you open CARVanta, you'll see a **sidebar on the left** with 9 modules. Here's what each one does:

---

### 🔬 1. Single Antigen Analysis

**What it does:** Deep-dive analysis of ONE specific antigen.

**How to use it:**
1. Type an antigen name in the search box (e.g., "CD19")
2. Select the antigen from the dropdown
3. Optionally select a specific cancer type
4. Click **"Analyze"**

**What you'll see:**
- **Core Metrics** — CVS Score, Adaptive Score (v4 blend), ML Ranking, Tier
- **Score Breakdown** — A radar chart showing each scoring component
- **Safety Profile** — Risk level, safety margin, toxicity flags
- **ML Prediction** — Whether the ML model thinks this target is viable, and how confident it is
- **AI Insights** — Auto-generated interpretation of the results
- **📥 Download PDF** — Export a professional report

**Example:** Search "CD19" with "Leukemia" → You'll see a Tier 1 score (~0.92) because CD19 is the gold standard CAR-T target for blood cancers.

---

### ⚖️ 2. Antigen Comparison

**What it does:** Compare 2 or more antigens side-by-side.

**How to use it:**
1. Select multiple antigens from the dropdown
2. Choose a cancer type
3. Click **"Compare"**

**What you'll see:**
- Side-by-side score comparison
- Visual bar charts showing which antigen scores higher on each metric
- A clear winner for the selected cancer type

**Use case:** "Should I target CD19 or CD22 for B-ALL?" → Compare them head-to-head.

---

### 🧫 3. Tissue Risk Heatmap

**What it does:** Shows how much an antigen is expressed in HEALTHY organs — this predicts **side effects**.

**How to use it:**
1. Select an antigen
2. Click **"Generate Heatmap"**

**What you'll see:**
- A table of organs (Heart, Brain, Liver, Lung, Kidney, etc.)
- Each organ gets a **risk score** from negligible to critical
- **⚠️ Critical Organ Alerts** — warnings if the target is highly expressed in vital organs
- **Safety Recommendation** — overall assessment

**Why it matters:** If CD19 is highly expressed in brain tissue, targeting it could cause neurological damage. This heatmap reveals those hidden dangers.

---

### 🎯 4. Multi-Target Synergy

**What it does:** Scores multi-antigen CAR-T combinations (targeting 2-4 antigens simultaneously).

**How to use it:**
1. Select 2-4 antigens
2. Click **"Score Combination"**

**What you'll see:**
- **Synergy Score** — How well the combination works together
- **Complementarity** — Do the antigens cover each other's weaknesses?
- **Escape Risk Reduction** — Can the cancer evade by downregulating one target?
- **Coverage** — What % of cancer cells are covered?
- **Aggregate Safety** — Combined toxicity risk

**Use case:** "Is CD19 + CD22 a better dual-target than CD19 alone?" → The synergy score will show if the combination reduces antigen escape risk.

---

### 👥 5. Patient Stratification

**What it does:** Predicts how different patient subgroups would respond to a specific CAR-T therapy.

**How to use it:**
1. Enter an antigen name
2. Enter a cancer type
3. Click **"Stratify"**

**What you'll see:**
- Patient subgroups (High Responders, Moderate, Low, Non-Responders)
- Biomarker profiles for each group
- Recommended patient selection criteria

**Use case:** "Which myeloma patients would benefit most from BCMA-targeted CAR-T?" → The tool identifies high-responder patient profiles.

---

### 🔍 6. NLP Query Search

**What it does:** Search for antigens using **plain English** instead of technical parameters.

**How to use it:**
1. Type a natural language query, like:
   - *"Find safe targets for leukemia"*
   - *"Best surface antigens for glioblastoma Tier 1 only"*
   - *"Top 10 immunogenic targets for melanoma with low toxicity"*
2. Click **"Search"**

**What you'll see:**
- **Query Interpretation** — What the AI understood from your query (cancer type, safety preference, tier filter)
- **Ranked Results** — Antigens matching your criteria, ranked by adaptive score
- **Search Engine** — Whether keyword or semantic search was used

**Why it's powerful:** Instead of manually filtering through 16,000 antigens, just describe what you need in plain English.

---

### 💊 7. Clinical Trials

**What it does:** Shows clinical trial information for a specific antigen.

**How to use it:**
1. Enter an antigen name
2. Click **"Search Trials"**

**What you'll see:**
- Number of registered trials
- Trial phases (Phase I, II, III)
- Cancer types being investigated
- Trial status and sponsors

---

### 🏆 8. Global Leaderboard

**What it does:** Ranks ALL antigens globally or per cancer type using the v4 adaptive scoring.

**How to use it:**
1. Select how many targets to show (10-100)
2. **Select a cancer type** (or "All Global")
3. Click **"Load Leaderboard"**

**What you'll see:**
- Ranked list of top antigens with Score, ML prediction, and Tier
- Different cancer types show DIFFERENT #1 targets:
  - **Leukemia** → CD19 is #1
  - **Multiple Myeloma** → BCMA is #1
  - **Neuroblastoma** → GD2 is #1
  - **Melanoma** → GD2/CSPG4 are top

**This is the flagship feature** — it demonstrates that CARVanta produces genuinely cancer-specific, intelligent rankings.

---

### 📊 9. System Status

**What it does:** Health check dashboard for the platform.

**What you'll see:**
- API status (online/offline)
- Version number (v4)
- Number of loaded antigens and cancer types
- Scoring engine details
- Available endpoints

---

## Architecture Overview

```
┌─────────────────────────────────────────────────────┐
│                    USER (Browser)                    │
│              Streamlit Frontend (Port 8501)          │
└───────────────────────┬─────────────────────────────┘
                        │ HTTP requests
                        ▼
┌─────────────────────────────────────────────────────┐
│               FastAPI Backend (Port 8001)            │
│  ┌─────────────┐  ┌──────────────┐  ┌────────────┐ │
│  │ Scoring      │  │ ML Models    │  │ NLP Query  │ │
│  │ Engine (CVS) │  │ (XGBoost +   │  │ Parser     │ │
│  │              │  │  RandomForest)│  │            │ │
│  └──────┬──────┘  └──────┬───────┘  └─────┬──────┘ │
│         │                │                │         │
│         └────────────────┼────────────────┘         │
│                          ▼                          │
│  ┌──────────────────────────────────────────────┐   │
│  │        Biomarker Database (120K+ rows)        │  │
│  │     data/biomarker_database.csv               │  │
│  └──────────────────────────────────────────────┘   │
└─────────────────────────────────────────────────────┘
```

---

## Quick Start

### 1. Start the API Server
```bash
cd C:\Users\dhruv\CARVanta
C:\Users\dhruv\carvanta_env\Scripts\python.exe -m uvicorn api.main:app --port 8001 --reload
```

### 2. Start the Frontend (separate terminal)
```bash
cd C:\Users\dhruv\CARVanta
C:\Users\dhruv\carvanta_env\Scripts\python.exe -m streamlit run frontend/app.py
```

### 3. Open in Browser
Go to **http://localhost:8501**

---

## Key Terminology Glossary

| Term | Plain English Meaning |
|---|---|
| **Antigen** | A protein on the surface of a cell. CAR-T cells are designed to recognize specific antigens on cancer cells |
| **CAR-T** | Chimeric Antigen Receptor T-cell — an immune cell engineered to fight cancer |
| **CVS** | CAR-T Viability Score — CARVanta's composite score combining multiple factors |
| **Tumor Specificity** | How much more the antigen appears on cancer cells vs. healthy cells. Higher = better |
| **Normal Expression** | How much the antigen appears on healthy tissue. Lower = safer |
| **Immunogenicity** | How strongly the immune system reacts to this antigen. Higher = more effective |
| **Surface Accessibility** | Whether the antigen is on the cell surface (where CAR-T can reach it) vs. inside the cell |
| **Stability Score** | How consistently the antigen is expressed. Stable = reliable target |
| **Literature Support** | How much published research exists for this target |
| **Therapeutic Index** | Ratio of tumor expression to normal expression — higher means safer |
| **Off-tumor toxicity** | Side effects from CAR-T attacking healthy cells that also have the antigen |
| **Antigen escape** | When cancer cells stop producing the target antigen to avoid being killed |

---

## What Makes CARVanta Unique?

1. **120,000+ Biomarker Database** — Not just a handful of targets; comprehensive coverage
2. **ML-Driven Adaptive Scoring** — XGBoost regression model trained on real biomarker features
3. **Cancer-Context Awareness** — Same antigen gets different scores for different cancers
4. **Natural Language Search** — Ask questions in plain English
5. **Multi-Target Synergy** — Score combination therapies, not just single targets
6. **Patient Stratification** — Predict who will respond best
7. **Professional PDF Reports** — Export findings for presentations and publications

---

*CARVanta v4 — AI-Powered CAR-T Cell Target Viability Assessment Platform*
*© CARVanta — carvanta.ai*

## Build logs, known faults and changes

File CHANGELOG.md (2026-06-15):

# Changelog

All notable changes to the CARVanta platform will be documented in this file.

## [5.1.0] — 2026-06-15

### 🔬 Sentinel HYDRA Hardware Release

#### Gerber Manufacturing Package
- **Production Gerber files** generated for 6-layer PCB via KiCad CLI
  - 6 copper layers: Digital_Signals (F.Cu), GND_Plane (In1), Analog_Signals (In2), Power_Planes (In3), HighSpeed (In4), Bottom_GND (B.Cu)
  - Front/Back solder mask, silkscreen, paste stencil, fabrication layers
  - Board outline (Edge.Cuts)
- **Excellon drill files** with PTH and NPTH separated
- **Drill map files** in Gerber X2 format
- **`Sentinel_HYDRA_Gerbers.zip`** — manufacturing-ready archive for JLCPCB/PCBWay upload

#### Board Statistics (from KiCad export)
- 135 components (123 SMD + 11 THT)
- 641 SMD pads + 72 through-hole pads + 9 NPTH
- 225 through-hole vias
- 1.6mm stackup thickness, ENIG surface finish

#### Dual-MCU Firmware (50 files, 114KB)
- **ESP32-S3 firmware** (`esp32_hydra/`) — WiFi, display, cloud, storage, power management
- **RP2040 firmware** (`rp2040_hydra/`) — Real-time sensor acquisition, PID control, spectral analysis
- UART inter-MCU protocol at 921600 baud with CRC

#### Documentation Overhaul
- **`README.md`** — Complete rewrite with Sentinel HYDRA hardware section, updated stats (117K+ LOC, 778 files), hardware badges, manufacturing files link, firmware build instructions, documentation index
- **`ARCHITECTURE.md`** — New comprehensive architecture document covering software stack, 6-layer PCB stackup, dual-MCU design, I2C bus topology, SPI bus sharing, power architecture, sensor subsystems, firmware structure, inter-MCU protocol, data flow, and deployment
- **`CODE_OF_CONDUCT.md`** — Full Contributor Covenant v2.1 with medical-adjacent patient safety commitments and enforcement guidelines
- **`contributing.md`** — Expanded guide covering software (Python/React), hardware (KiCad PCB design rules), and firmware (PlatformIO ESP32/RP2040) contributions, PR process, commit convention
- **`security.md`** — Expanded security policy with version support matrix, hardware security considerations, HIPAA alignment, CVSS severity classification, and response timelines

---

## [5.0.0] — 2026-03-16

### 🚀 International Recognition Roadmap Release

#### New Backend Modules
- **`api/audit_logger.py`** — SQLite-backed audit logging middleware for HIPAA compliance
- **`features/drug_interactions.py`** — Drug-antigen interaction checker (13 antigens, ~30 drugs)
- **`features/explainability.py`** — SHAP-based explainability with TreeExplainer + fallback
- **`features/fhir_export.py`** — FHIR R4 DiagnosticReport/Observation bundle export
- **`features/ip_landscape.py`** — Curated patent landscape data for 9 key antigens
- **`features/notation_standards.py`** — HUGO/NCBI/UniProt/Ensembl gene ID mappings (20 antigens)
- **`features/score_history.py`** — SQLite-backed score time-series tracker

#### New Regulatory Documents
- **`PRIVACY_POLICY.md`** — HIPAA compliance disclosure and privacy policy
- **`ISO_13485_ALIGNMENT.md`** — ISO 13485 quality management alignment report
- **`MODEL_CARD.md`** — Google-standard model card documentation

#### New API Endpoints (20 total)
- `GET /api/drug-interactions/{antigen}` — Drug interaction check
- `GET /api/drug-interactions` — All catalogued interactions
- `GET /api/explain/{antigen}` — SHAP explainability
- `POST /api/batch-upload` — Score up to 500 genes
- `GET /api/model-card` — Model card (JSON)
- `GET /api/cite/{antigen}` — Citation generator (APA/MLA/BibTeX/RIS)
- `GET /api/audit-log` — Regulatory audit trail
- `GET /api/fhir/{antigen}` — FHIR R4 export
- `GET /api/patents/{antigen}` — Patent landscape
- `GET /api/patents` — All patent summaries
- `GET /api/gene-ids/{antigen}` — Gene notation lookup
- `GET /api/gene-ids` — All gene identifiers
- `GET /api/score-history/{antigen}` — Historical scores
- `GET /api/score-history` — All tracked antigens
- `POST /api/score-snapshot` — Record score snapshot
- `POST /api/community/submit` — Community antigen submission
- `GET /api/dataset/benchmarks` — Published benchmarks
- `GET /api/privacy-policy` — Privacy policy (JSON)
- `GET /api/sdk-info` — API marketplace info

#### New Frontend Pages (5 total)
- **Drug Interactions** — Browse all antigen-drug interactions with risk levels
- **Patent Explorer** — Patent landscape with FTO assessments
- **Community Submit** — Submit new antigens for automated scoring
- **Batch Upload** — Score up to 500 genes at once with tier distribution
- **Audit Log** — Regulatory compliance request viewer with stats

#### Enhanced Single Analysis Page
- Gene ID badges (HUGO/NCBI/UniProt/Ensembl + external links)
- Drug interaction warning cards with risk-level coloring
- SHAP explainability bars with narrative explanation
- Patent landscape badge (FTO + key patents)
- Score history timeline with trend indicator
- Citation modal (APA/MLA/BibTeX/RIS + copy-to-clipboard)
- FHIR R4 JSON export button
- Save Snapshot button for time-series tracking

#### Frontend Improvements
- Dark/Light mode toggle with localStorage persistence
- PWA manifest for mobile installability
- Apple mobile web app meta tags
- Updated version to v5

#### Configuration
- Added `pyrightconfig.json` to suppress false-positive linter errors
- Added `shap>=0.43.0` to `requirements.txt`

## [4.0.0] — 2026-02-27

### ML & Data Upgrade
- Replaced synthetic data with 100K+ real biomarkers (TCGA/GTEx)
- Trained Random Forest + XGBoost ensemble models
- Implemented 8-feature Clinical Viability Score (CVS) engine
- Added benchmark validation against FDA-approved CAR-T targets

## [3.0.0] — 2026-02-25

### Platform Launch
- React frontend with 10 pages
- FastAPI backend with scoring, safety, and analysis endpoints
- Patient stratification and multi-target synergy analysis
- NLP query search and clinical trials integration

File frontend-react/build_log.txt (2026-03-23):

[36mvite v7.3.1 [32mbuilding client environment for production...[36m[39m
transforming...
[32mΓ£ô[39m 114 modules transformed.
rendering chunks...
computing gzip size...
[2mdist/[22m[32mindex.html                 [39m[1m[2m  0.84 kB[22m[1m[22m[2m Γöé gzip:   0.54 kB[22m
[2mdist/[22m[35massets/index-fJjbfSWc.css  [39m[1m[2m  9.74 kB[22m[1m[22m[2m Γöé gzip:   2.55 kB[22m
[2mdist/[22m[36massets/index-Diyd3AP8.js   [39m[1m[2m466.62 kB[22m[1m[22m[2m Γöé gzip: 153.34 kB[22m
[32mΓ£ô built in 32.18s[39m

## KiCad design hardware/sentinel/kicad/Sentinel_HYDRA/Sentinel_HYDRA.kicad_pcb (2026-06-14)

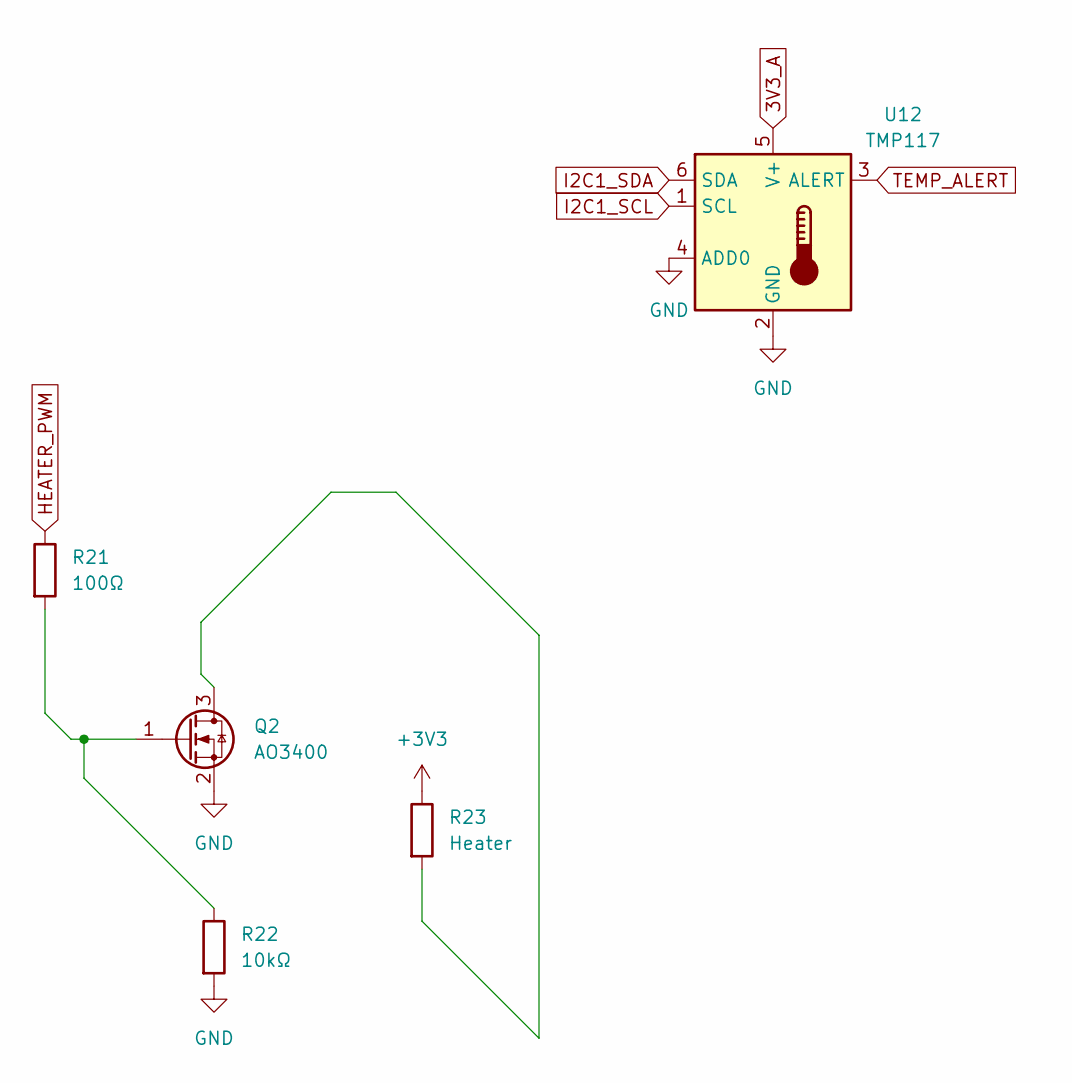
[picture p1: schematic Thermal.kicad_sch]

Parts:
Q2: AO3400; SOT-23
R21: 100Ω; R_0402_1005Metric
R22: 10kΩ; R_0402_1005Metric
R23: Heater
U12: TMP117; WSON-6-1EP_2x2mm_P0.65mm_EP1x1.6mm

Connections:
3V3_A: U12.5 (V+); also elsewhere on the board
+3V3: Q2.2 (S), Q2.3 (D), R22.2, R23.2, U12.2 (GND), U12.4 (ADD0); also elsewhere on the board
HEATER_PWM: R21.1; also elsewhere on the board
I2C1_SCL: U12.1 (SCL); also elsewhere on the board
I2C1_SDA: U12.6 (SDA); also elsewhere on the board
unnamed: Q2.1 (G), R21.2, R22.1
TEMP_ALERT: U12.3 (ALERT)

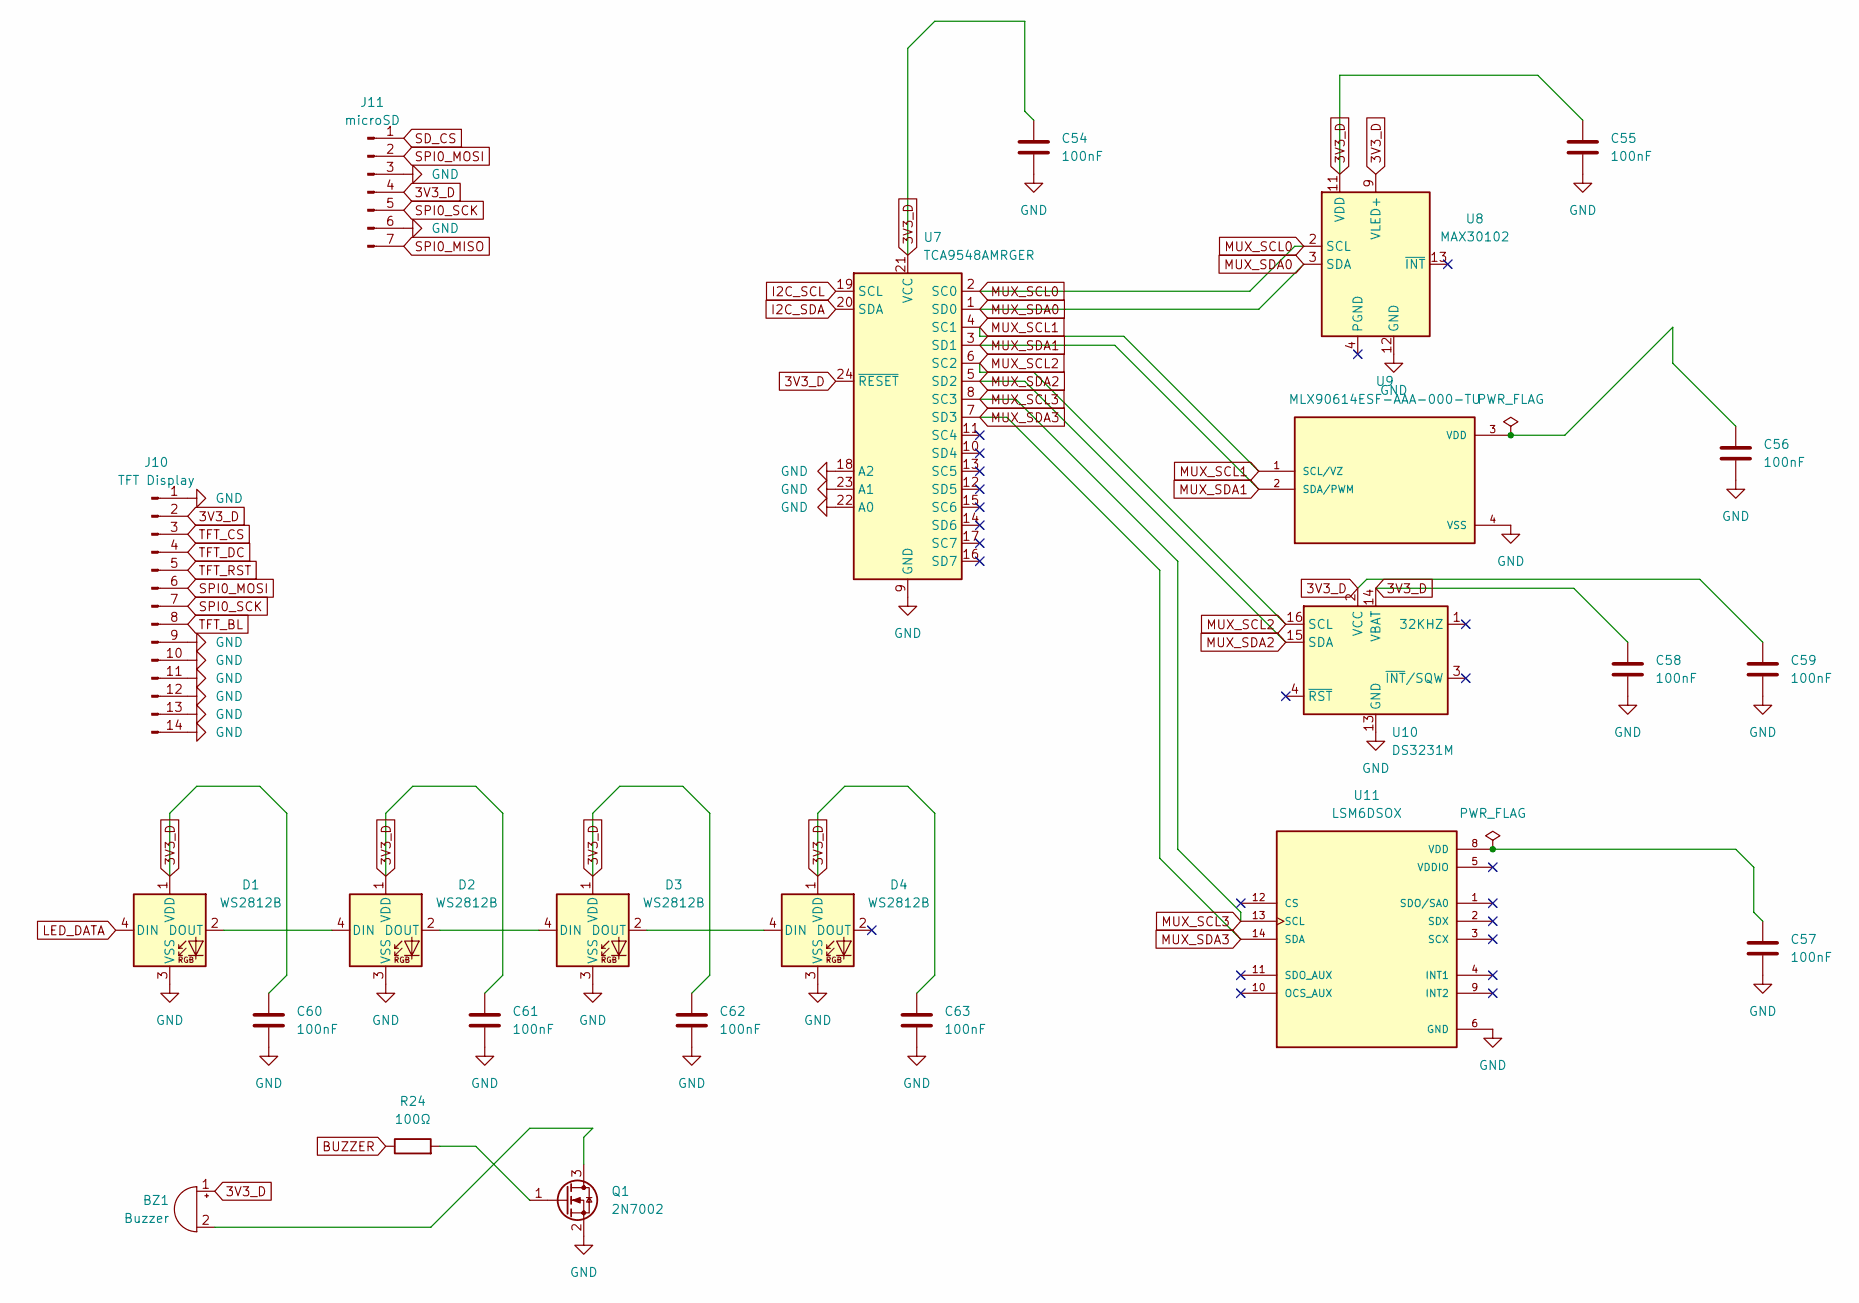
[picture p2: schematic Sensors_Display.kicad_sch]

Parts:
BZ1: Buzzer; Buzzer_12x9.5RM7.6
C54, C55, C56, C57, C58, C59, C60, C61, C62, C63: 100nF; C_0402_1005Metric
D1, D2, D3, D4: WS2812B; LED_WS2812B_PLCC4_5.0x5.0mm_P3.2mm
J10: TFT Display; Hirose_FH12-14S-0.5SH_1x14-1MP_P0.50mm_Horizontal
J11: microSD; microSD_HC_Molex_104031-0811
Q1: 2N7002; SOT-23
R24: 100Ω; R_0402_1005Metric
U7: TCA9548AMRGER; Texas_RGE0024C_VQFN-24-1EP_4x4mm_P0.5mm_EP2.1x2.1mm
U8: MAX30102; Maxim_OLGA-14_3.3x5.6mm_P0.8mm
U9: MLX90614ESF-AAA-000-TU; TO254P912H435-4; PARTREV 13
U10: DS3231M; SOIC-16W_7.5x10.3mm_P1.27mm
U11: LSM6DSOX; PQFN50P250X300X86-14N; PARTREV 3.0

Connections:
3V3_D: BZ1.1 (+), C54.1, C55.1, C58.1, C59.1, C60.1, C61.1, C62.1, C63.1, D1.1 (VDD), D2.1 (VDD), D3.1 (VDD), D4.1 (VDD), J10.2, J11.4, U7.21 (VCC), U7.24 (~RESET), U8.9 (VLED+), U8.10 (VLED+), U8.11 (VDD), U10.2 (VCC), U10.14 (VBAT); also elsewhere on the board
+3V3: C54.2, C55.2, C56.2, C57.2, C58.2, C59.2, C60.2, C61.2, C62.2, C63.2, D1.3 (VSS), D2.3 (VSS), D3.3 (VSS), D4.3 (VSS), J10.1, J10.9, J10.10, J10.11, J10.12, J10.13, J10.14, J11.3, J11.6, Q1.2 (S), U7.9 (GND), U7.18 (A2), U7.22 (A0), U7.23 (A1), U8.12 (GND), U9.4 (VSS), U10.5 (GND), U10.6 (GND), U10.7 (GND), U10.8 (GND), U10.9 (GND), U10.10 (GND), U10.11 (GND), U10.12 (GND), U10.13 (GND), U11.6 (GND), U11.7 (GND); also elsewhere on the board
BUZZER: R24.1; also elsewhere on the board
I2C_SCL: U7.19 (SCL); also elsewhere on the board
I2C_SDA: U7.20 (SDA); also elsewhere on the board
LED_DATA: D1.4 (DIN); also elsewhere on the board
MUX_SCL0: U7.2 (SC0), U8.2 (SCL)
MUX_SCL1: U7.4 (SC1), U9.1 (SCL/VZ)
MUX_SCL2: U7.6 (SC2), U10.16 (SCL)
MUX_SCL3: U7.8 (SC3), U11.13 (SCL)
MUX_SDA0: U7.1 (SD0), U8.3 (SDA)
MUX_SDA1: U7.3 (SD1), U9.2 (SDA/PWM)
MUX_SDA2: U7.5 (SD2), U10.15 (SDA)
MUX_SDA3: U7.7 (SD3), U11.14 (SDA)
unnamed: BZ1.2 (-), Q1.3 (D)
unnamed: D1.2 (DOUT), D2.4 (DIN)
unnamed: D2.2 (DOUT), D3.4 (DIN)
unnamed: D3.2 (DOUT), D4.4 (DIN)
unnamed: Q1.1 (G), R24.2
unnamed: C56.1, U9.3 (VDD)
unnamed: C57.1, U11.8 (VDD)
SD_CS: J11.1; also elsewhere on the board
SPI0_MISO: J11.7; also elsewhere on the board
SPI0_MOSI: J10.6, J11.2; also elsewhere on the board
SPI0_SCK: J10.7, J11.5; also elsewhere on the board
TFT_BL: J10.8; also elsewhere on the board
TFT_CS: J10.3; also elsewhere on the board
TFT_DC: J10.4; also elsewhere on the board
TFT_RST: J10.5; also elsewhere on the board

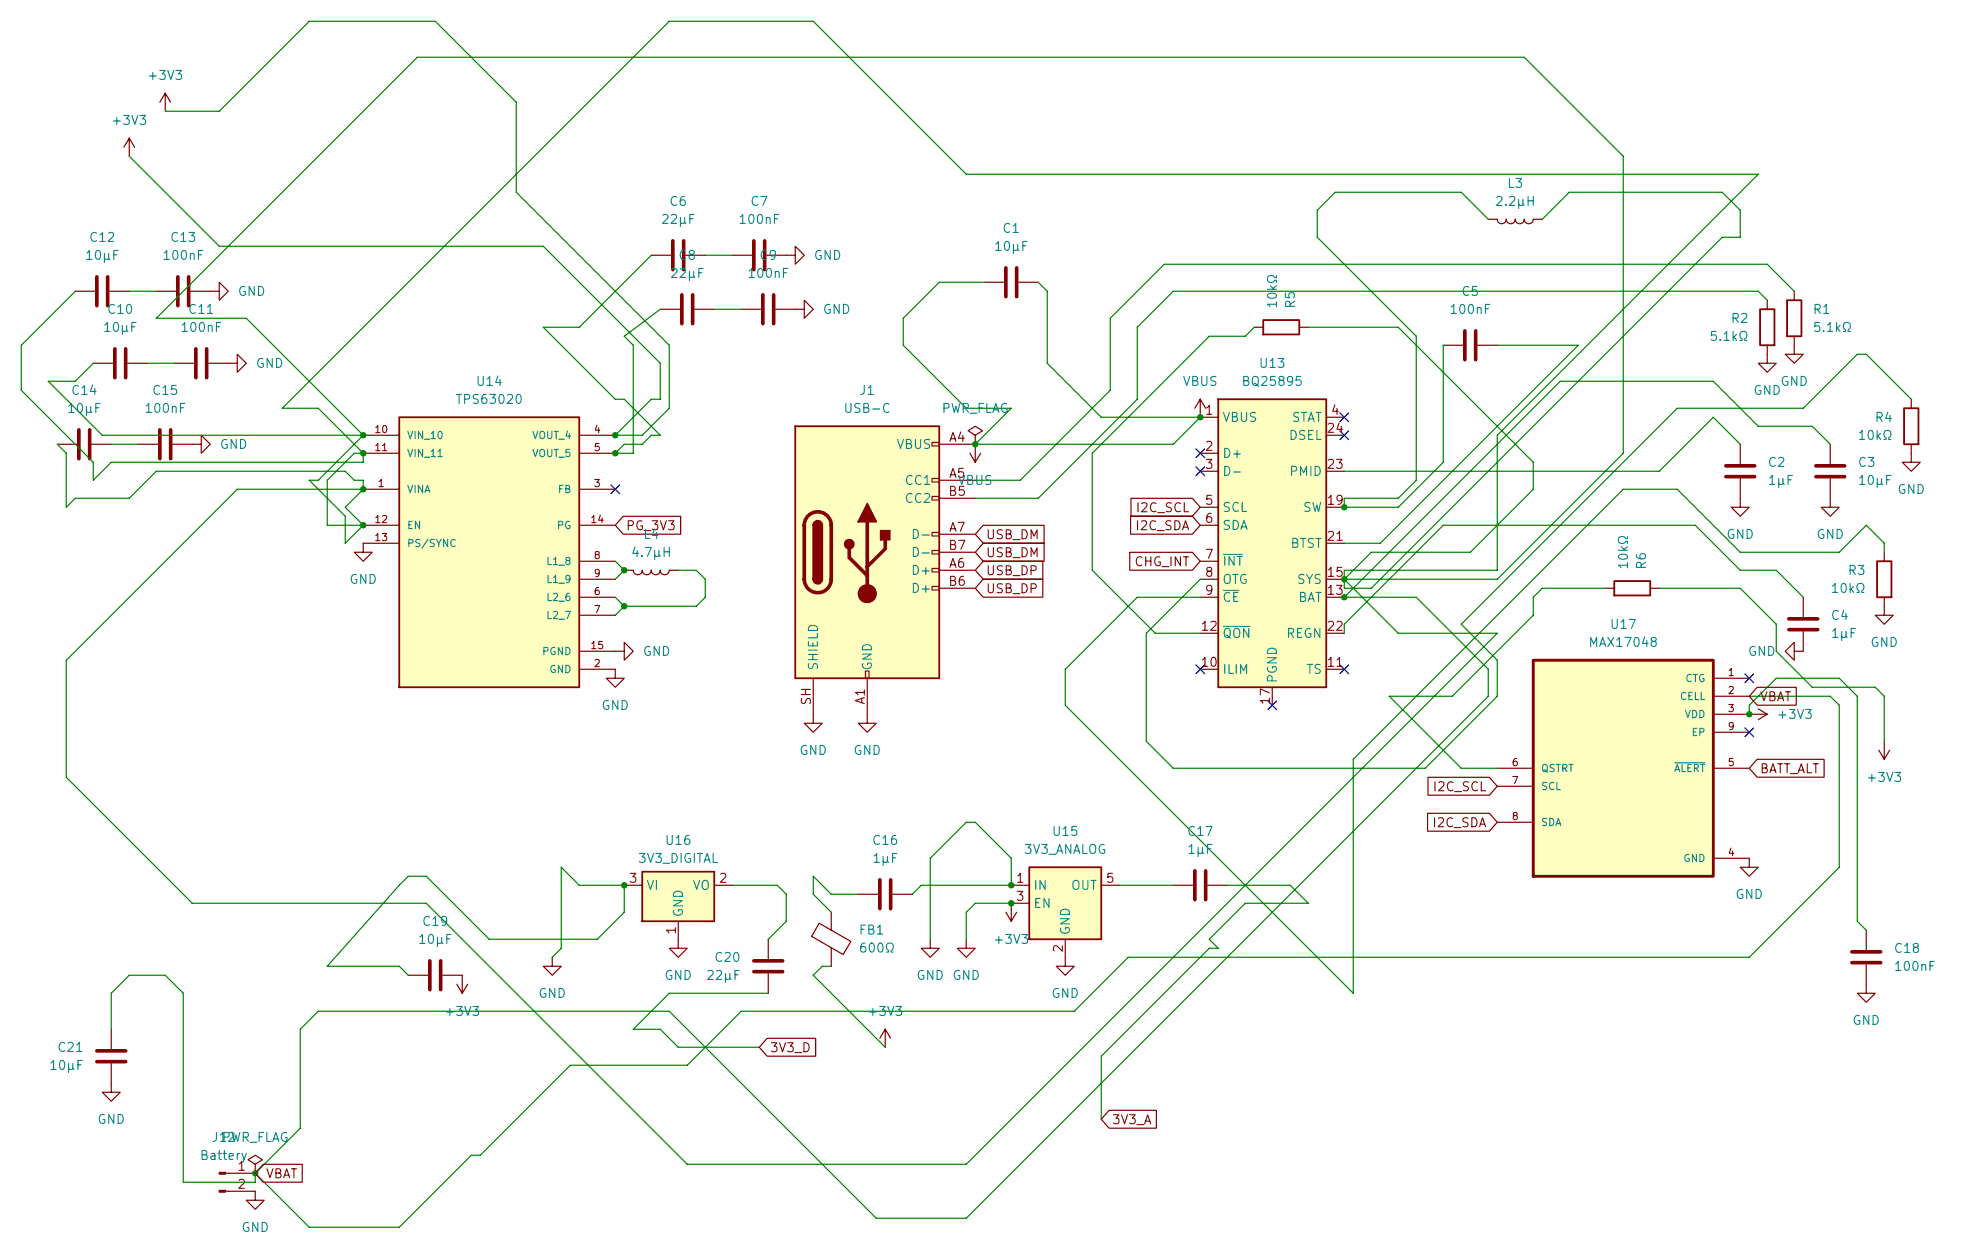
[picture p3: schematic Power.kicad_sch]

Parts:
C1, C3, C10, C12, C14, C19, C21: 10µF; C_0805_2012Metric
C2, C4, C16, C17: 1µF; C_0402_1005Metric
C5, C7, C9, C11, C13, C15, C18: 100nF; C_0402_1005Metric
C6, C8, C20: 22µF; C_0805_2012Metric
FB1: 600Ω; L_0402_1005Metric
J1: USB-C; USB_C_Receptacle_HRO_TYPE-C-31-M-12
J12: Battery; JST_PH_B2B-PH-K_1x02_P2.00mm_Vertical
L3: 2.2µH; L_Taiyo-Yuden_NR-40xx
L4: 4.7µH; L_Taiyo-Yuden_NR-40xx
R1, R2: 5.1kΩ; R_0402_1005Metric
R3, R4, R5, R6: 10kΩ; R_0402_1005Metric
U13: BQ25895; Texas_RTW_WQFN-24-1EP_4x4mm_P0.5mm_EP2.7x2.7mm_ThermalVias
U14: TPS63020; IC_TPS63020DSJR
U15: 3V3_ANALOG; SOT-23-5
U16: 3V3_DIGITAL; SOT-223-3_TabPin2
U17: MAX17048; SON50P200X200X80-9N

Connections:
3V3_A: C17.1; also elsewhere on the board
3V3_D: C20.2; also elsewhere on the board
+3V3: C2.1, C3.1, C4.1, C7.1, C9.1, C11.1, C13.1, C15.1, C16.1, C18.1, C18.2, C19.1, C19.2, C21.2, FB1.2, J1.A1 (GND), J1.A12 (GND), J1.B1 (GND), J1.B12 (GND), J1.SH (SHIELD), J12.2, R1.2, R2.2, R3.2, R4.2, R6.1, U14.2 (GND), U14.4 (VOUT_4), U14.13 (PS/SYNC), U14.15 (PGND), U15.1 (IN), U15.2 (GND), U15.3 (EN), U16.1 (GND), U16.3 (VI), U17.3 (VDD), U17.4 (GND); also elsewhere on the board
BATT_ALT: U17.5 (~ALERT); also elsewhere on the board
CHG_INT: U13.7 (~INT); also elsewhere on the board
I2C_SCL: U13.5 (SCL), U17.7 (SCL); also elsewhere on the board
I2C_SDA: U13.6 (SDA), U17.8 (SDA); also elsewhere on the board
unnamed: C5.1, L3.2, U13.19 (SW), U13.20 (SW)
unnamed: C6.1, C7.2
unnamed: C8.1, C9.2
unnamed: C10.1, C11.2
unnamed: C12.1, C13.2
unnamed: C14.1, C15.2
unnamed: C16.2, FB1.1
unnamed: J1.A5 (CC1), R1.1
unnamed: J1.B5 (CC2), R2.1
unnamed: C5.2, U13.21 (BTST)
unnamed: R4.1, U13.8 (OTG)
unnamed: C2.2, U13.23 (PMID)
unnamed: C4.2, U13.22 (REGN)
unnamed: R3.1, U13.9 (~CE)
unnamed: R5.2, U13.12 (~QON)
unnamed: C10.2, C12.2, C14.2, L3.1, R5.1, U13.15 (SYS), U13.16 (SYS), U14.1 (VINA), U14.10 (VIN_10), U14.11 (VIN_11), U14.12 (EN)
unnamed: L4.2, U14.8 (L1_8), U14.9 (L1_9)
unnamed: C6.2, C8.2, U14.5 (VOUT_5)
unnamed: C17.2, U15.5 (OUT)
unnamed: C20.1, U16.2 (VO)
unnamed: R6.2, U17.6 (QSTRT)
PG_3V3: U14.14 (PG); also elsewhere on the board
USB_DM: J1.A7 (D-), J1.B7 (D-); also elsewhere on the board
USB_DP: J1.A6 (D+), J1.B6 (D+); also elsewhere on the board
VBAT: C3.2, C21.1, J12.1, U13.13 (BAT), U13.14 (BAT), U17.2 (CELL)
VBUS: C1.1, C1.2, J1.A4 (VBUS), J1.A9 (VBUS), J1.B4 (VBUS), J1.B9 (VBUS), U13.1 (VBUS)

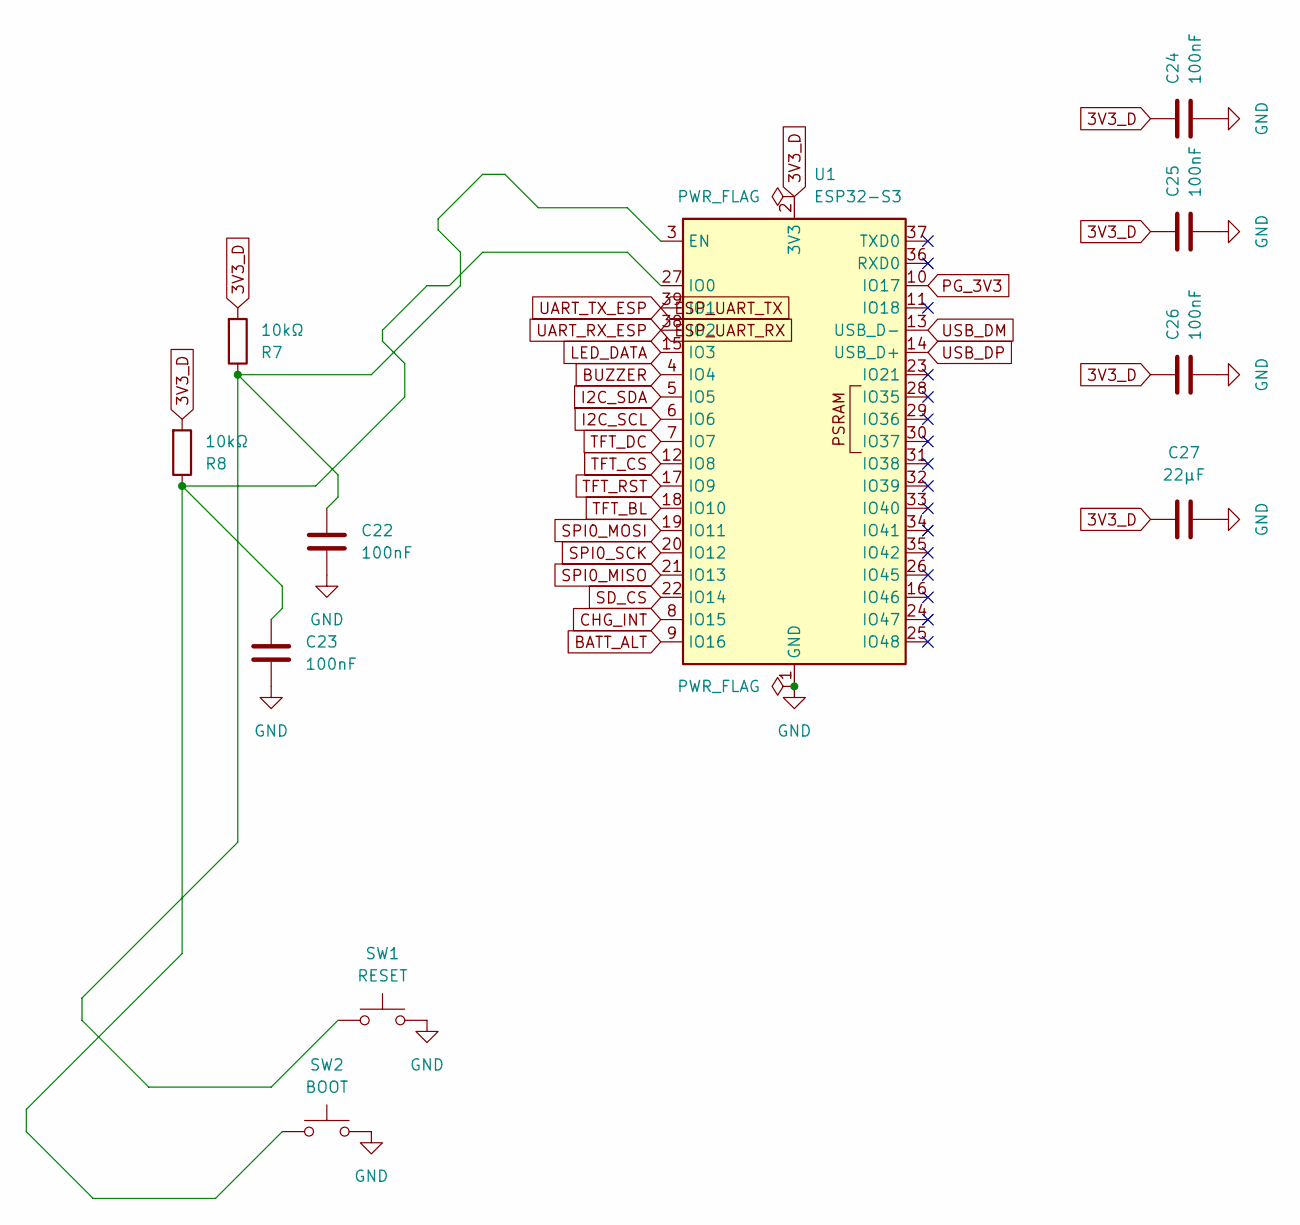
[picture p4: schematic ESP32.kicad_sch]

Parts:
C22, C23, C24, C25, C26: 100nF; C_0402_1005Metric
C27: 22µF; C_0805_2012Metric
R7, R8: 10kΩ; R_0402_1005Metric
SW1: RESET; SW_SPST_TL3342
SW2: BOOT; SW_SPST_TL3342
U1: ESP32-S3; ESP32-S3-WROOM-1

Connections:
3V3_D: C24.1, C25.1, C26.1, C27.1, R7.2, R8.2, U1.2 (3V3); also elsewhere on the board
+3V3: C22.2, C23.2, C24.2, C25.2, C26.2, C27.2, SW1.2, SW2.2, U1.1 (GND), U1.40 (GND), U1.41 (GND); also elsewhere on the board
BATT_ALT: U1.9 (IO16); also elsewhere on the board
BUZZER: U1.4 (IO4); also elsewhere on the board
CHG_INT: U1.8 (IO15); also elsewhere on the board
ESP_UART_RX: U1.38 (IO2); also elsewhere on the board
ESP_UART_TX: U1.39 (IO1); also elsewhere on the board
I2C_SCL: U1.6 (IO6); also elsewhere on the board
I2C_SDA: U1.5 (IO5); also elsewhere on the board
LED_DATA: U1.15 (IO3); also elsewhere on the board
unnamed: C22.1, R7.1, SW1.1, U1.3 (EN)
unnamed: C23.1, R8.1, SW2.1, U1.27 (IO0)
PG_3V3: U1.10 (IO17); also elsewhere on the board
SD_CS: U1.22 (IO14); also elsewhere on the board
SPI0_MISO: U1.21 (IO13); also elsewhere on the board
SPI0_MOSI: U1.19 (IO11); also elsewhere on the board
SPI0_SCK: U1.20 (IO12); also elsewhere on the board
TFT_BL: U1.18 (IO10); also elsewhere on the board
TFT_CS: U1.12 (IO8); also elsewhere on the board
TFT_DC: U1.7 (IO7); also elsewhere on the board
TFT_RST: U1.17 (IO9); also elsewhere on the board
USB_DM: U1.13 (USB_D-); also elsewhere on the board
USB_DP: U1.14 (USB_D+); also elsewhere on the board

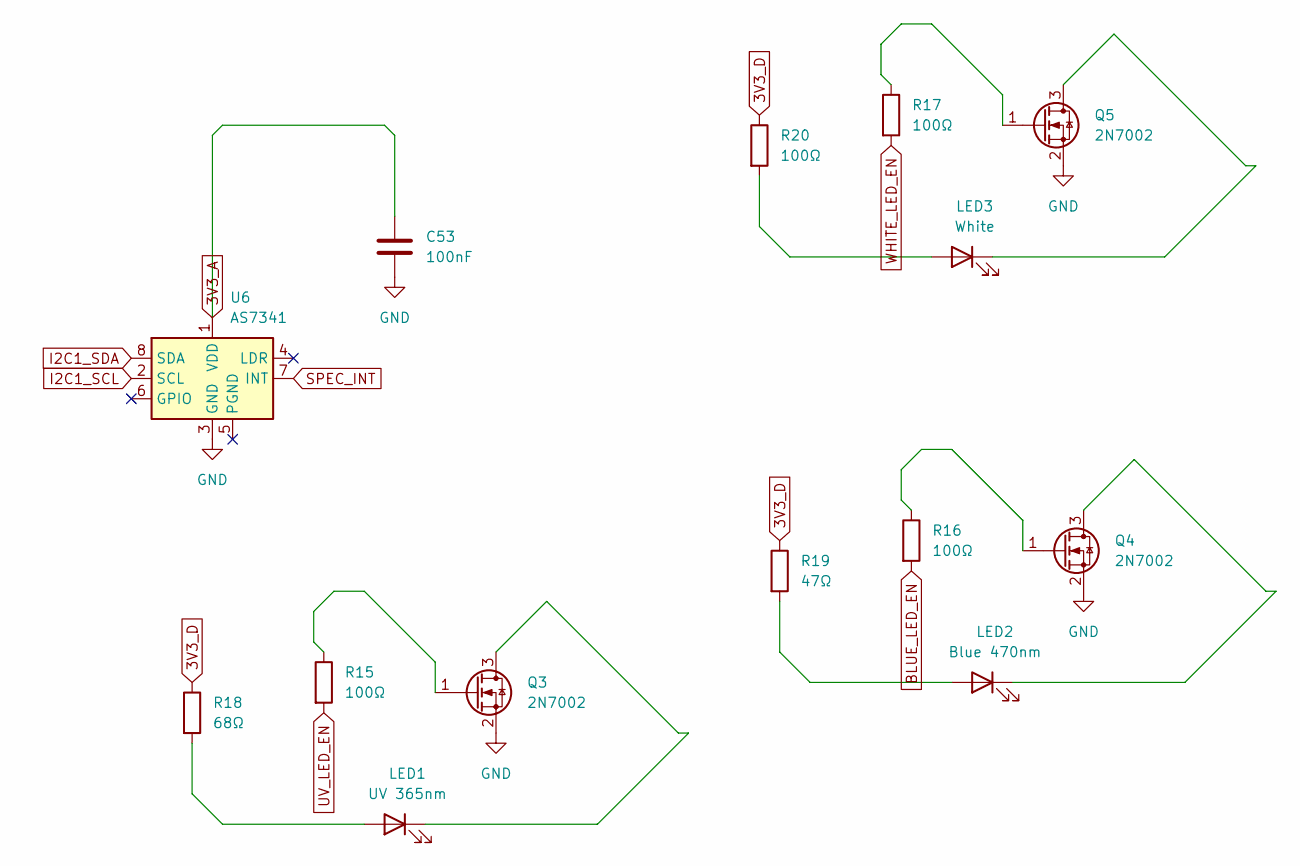
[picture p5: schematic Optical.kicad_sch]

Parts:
C53: 100nF; C_0402_1005Metric
LED1: UV 365nm; LED_0805_2012Metric
LED2: Blue 470nm; LED_0805_2012Metric
LED3: White; LED_0805_2012Metric
Q3, Q4, Q5: 2N7002; SOT-23
R15, R16, R17, R20: 100Ω; R_0402_1005Metric
R18: 68Ω; R_0402_1005Metric
R19: 47Ω; R_0402_1005Metric
U6: AS7341; AMS_OLGA-8_2x3.1mm_P0.8mm

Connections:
3V3_A: C53.1, U6.1 (VDD); also elsewhere on the board
3V3_D: R18.1, R19.1, R20.1; also elsewhere on the board
+3V3: C53.2, Q3.2 (S), Q4.2 (S), Q5.2 (S), U6.3 (GND); also elsewhere on the board
BLUE_LED_EN: R16.2; also elsewhere on the board
I2C1_SCL: U6.2 (SCL); also elsewhere on the board
I2C1_SDA: U6.8 (SDA); also elsewhere on the board
unnamed: LED1.2 (A), R18.2
unnamed: LED1.1 (K), Q3.3 (D)
unnamed: LED2.2 (A), R19.2
unnamed: LED2.1 (K), Q4.3 (D)
unnamed: LED3.2 (A), R20.2
unnamed: LED3.1 (K), Q5.3 (D)
unnamed: Q3.1 (G), R15.1
unnamed: Q4.1 (G), R16.1
unnamed: Q5.1 (G), R17.1
SPEC_INT: U6.7 (INT); also elsewhere on the board
UV_LED_EN: R15.2; also elsewhere on the board
WHITE_LED_EN: R17.2; also elsewhere on the board

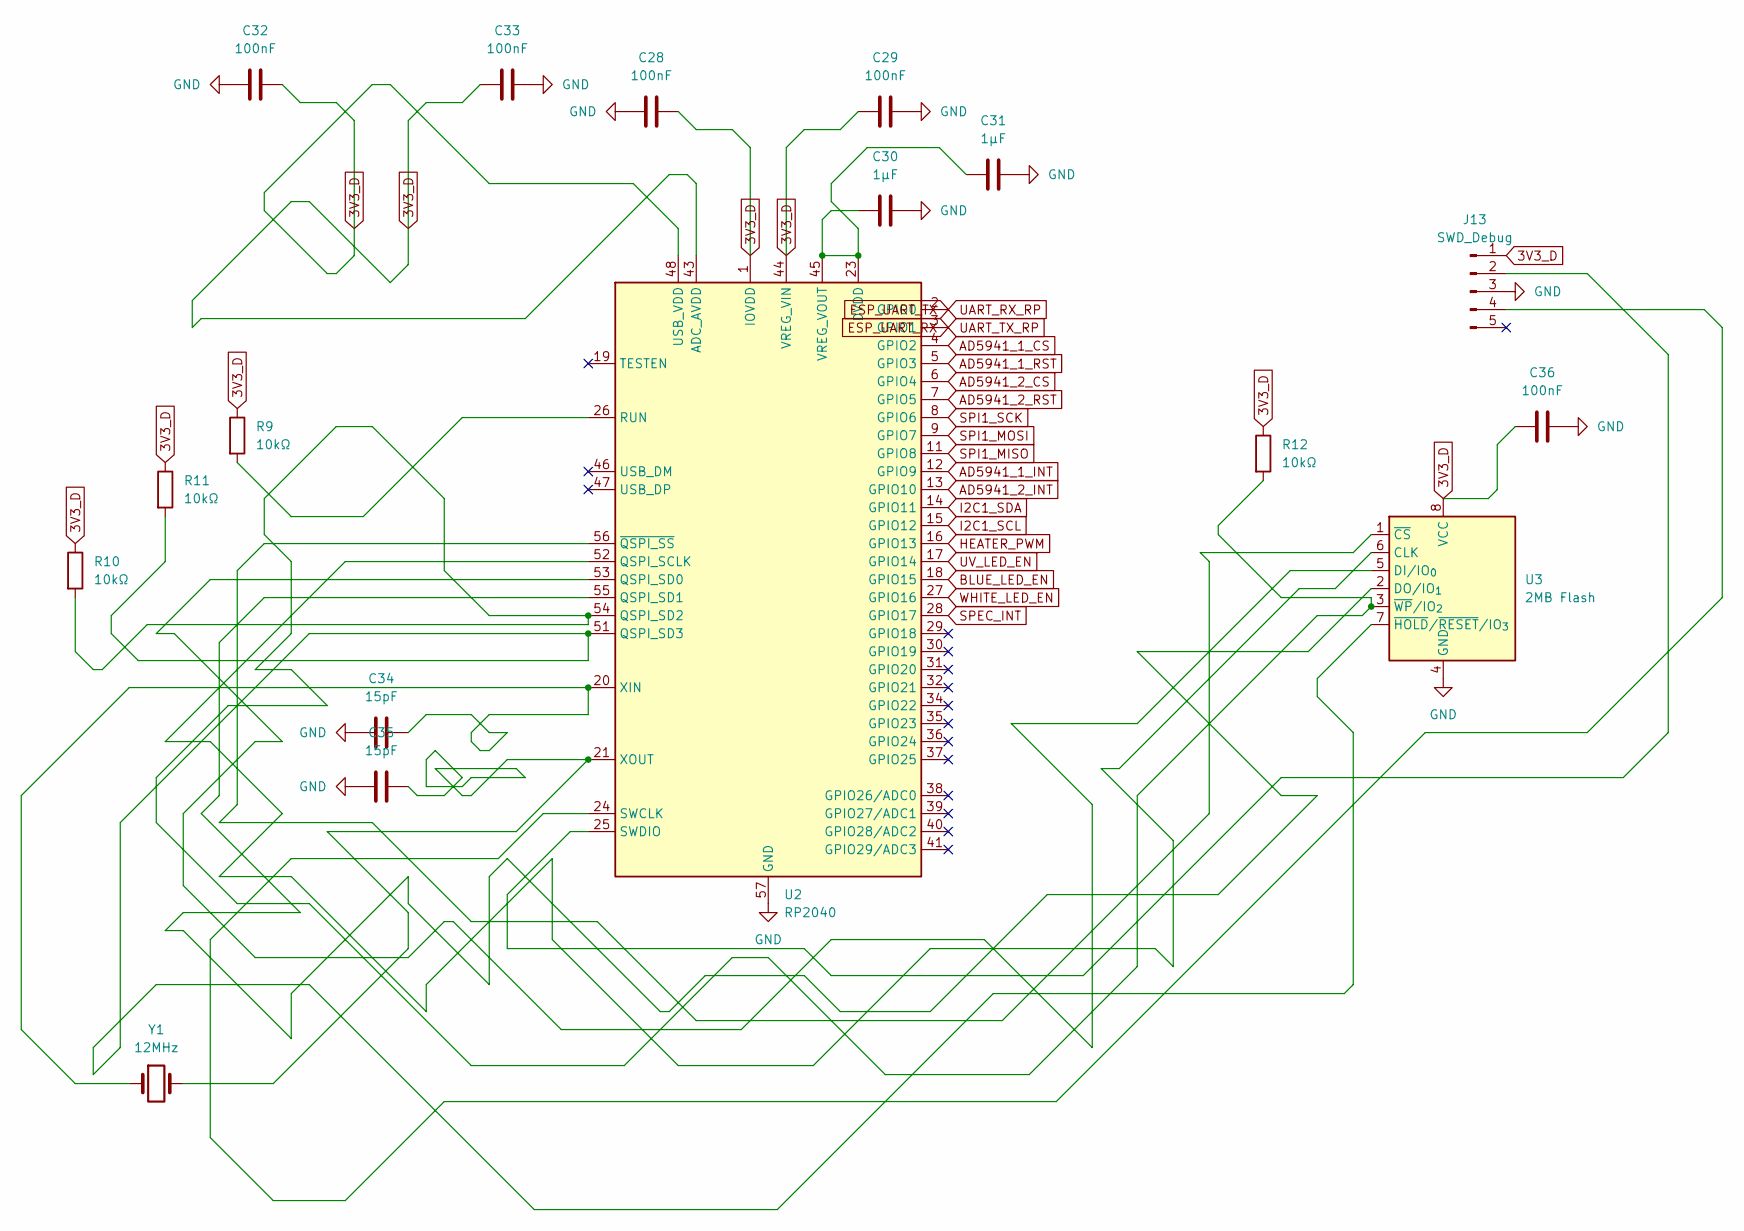
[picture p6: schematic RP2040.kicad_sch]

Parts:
C28, C29, C32, C33, C36: 100nF; C_0402_1005Metric
C30, C31: 1µF; C_0402_1005Metric
C34, C35: 15pF; C_0402_1005Metric
J13: SWD_Debug; Tag-Connect_TC2050-IDC-FP_2x05_P1.27mm_Vertical
R9, R10, R11, R12: 10kΩ; R_0402_1005Metric
U2: RP2040; QFN-56-1EP_7x7mm_P0.4mm_EP3.2x3.2mm
U3: 2MB Flash; SOIC-8_3.9x4.9mm_P1.27mm
Y1: 12MHz; Crystal_SMD_3215-2Pin_3.2x1.5mm

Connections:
3V3_D: C28.1, C29.1, C32.1, C33.1, C36.1, J13.1, R9.1, R10.1, R11.1, R12.1, U2.1 (IOVDD), U2.10 (IOVDD), U2.22 (IOVDD), U2.33 (IOVDD), U2.42 (IOVDD), U2.43 (ADC_AVDD), U2.44 (VREG_VIN), U2.48 (USB_VDD), U2.49 (IOVDD), U3.8 (VCC); also elsewhere on the board
+3V3: C28.2, C29.2, C30.2, C31.2, C32.2, C33.2, C34.2, C35.2, C36.2, J13.3, U2.57 (GND), U3.4 (GND); also elsewhere on the board
AD5941_1_CS: U2.4 (GPIO2); also elsewhere on the board
AD5941_1_INT: U2.12 (GPIO9); also elsewhere on the board
AD5941_1_RST: U2.5 (GPIO3); also elsewhere on the board
AD5941_2_CS: U2.6 (GPIO4); also elsewhere on the board
AD5941_2_INT: U2.13 (GPIO10); also elsewhere on the board
AD5941_2_RST: U2.7 (GPIO5); also elsewhere on the board
BLUE_LED_EN: U2.18 (GPIO15); also elsewhere on the board
ESP_UART_RX: U2.3 (GPIO1); also elsewhere on the board
ESP_UART_TX: U2.2 (GPIO0); also elsewhere on the board
HEATER_PWM: U2.16 (GPIO13); also elsewhere on the board
I2C1_SCL: U2.15 (GPIO12); also elsewhere on the board
I2C1_SDA: U2.14 (GPIO11); also elsewhere on the board
unnamed: J13.2, U2.25 (SWDIO)
unnamed: J13.4, U2.24 (SWCLK)
unnamed: U2.52 (QSPI_SCLK), U3.6 (CLK)
unnamed: U2.53 (QSPI_SD0), U3.5 (DI/IO_{0})
unnamed: U2.55 (QSPI_SD1), U3.2 (DO/IO_{1})
unnamed: R10.2, R12.2, U2.54 (QSPI_SD2), U3.3 (~WP/IO_{2})
unnamed: R11.2, U2.51 (QSPI_SD3), U3.7 (~HOLD/~RESET/IO_{3})
unnamed: R9.2, U2.26 (RUN)
unnamed: C30.1, C31.1, U2.23 (DVDD), U2.45 (VREG_VOUT), U2.50 (DVDD)
unnamed: C34.1, U2.20 (XIN), Y1.1
unnamed: C35.1, U2.21 (XOUT), Y1.2
unnamed: U2.56 (~QSPI_SS), U3.1 (~CS)
SPEC_INT: U2.28 (GPIO17); also elsewhere on the board
SPI1_MISO: U2.11 (GPIO8); also elsewhere on the board
SPI1_MOSI: U2.9 (GPIO7); also elsewhere on the board
SPI1_SCK: U2.8 (GPIO6); also elsewhere on the board
UV_LED_EN: U2.17 (GPIO14); also elsewhere on the board
WHITE_LED_EN: U2.27 (GPIO16); also elsewhere on the board

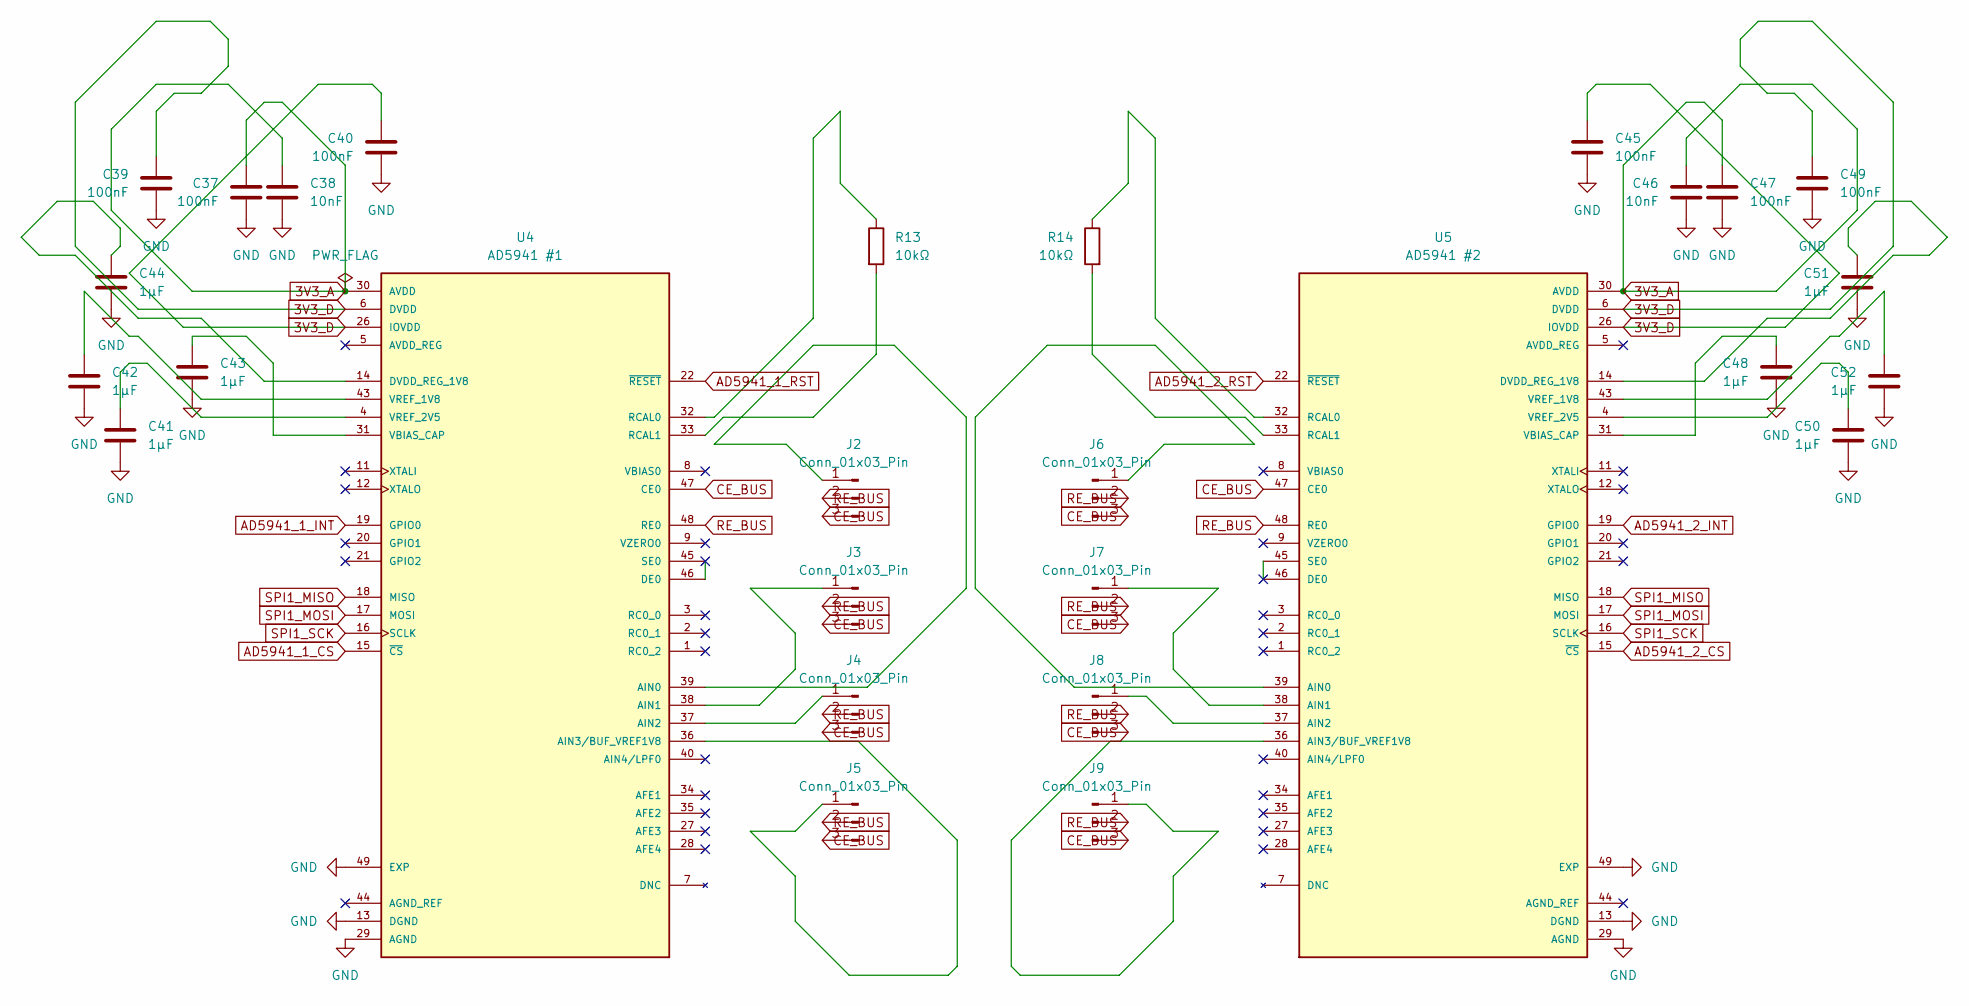
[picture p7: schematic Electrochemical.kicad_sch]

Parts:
C37, C39, C40, C45, C47, C49: 100nF; C_0402_1005Metric
C38, C46: 10nF; C_0402_1005Metric
C41, C42, C43, C44, C48, C50, C51, C52: 1µF; C_0402_1005Metric
J2, J3, J4, J5, J6, J7, J8, J9: Conn_01x03_Pin; Molex_PicoBlade_53047-0310_1x03_P1.25mm_Vertical
R13, R14: 10kΩ; R_0402_1005Metric
U4: AD5941 #1; QFN50P700X700X80-49N; PARTREV B
U5: AD5941 #2; QFN50P700X700X80-49N; PARTREV B

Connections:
3V3_A: C37.1, C38.1, C46.1, C47.1, U4.30 (AVDD), U4.41 (AVDD), U5.30 (AVDD), U5.41 (AVDD); also elsewhere on the board
3V3_D: C39.1, C40.1, C45.1, C49.1, U4.6 (DVDD), U4.26 (IOVDD), U5.6 (DVDD), U5.26 (IOVDD); also elsewhere on the board
+3V3: C37.2, C38.2, C39.2, C40.2, C41.2, C42.2, C43.2, C44.2, C45.2, C46.2, C47.2, C48.2, C49.2, C50.2, C51.2, C52.2, U4.13 (DGND), U4.23 (DGND), U4.25 (DGND), U4.29 (AGND), U4.42 (AGND), U4.49 (EXP), U5.13 (DGND), U5.23 (DGND), U5.25 (DGND), U5.29 (AGND), U5.42 (AGND), U5.49 (EXP); also elsewhere on the board
AD5941_1_CS: U4.15 (~CS); also elsewhere on the board
AD5941_1_INT: U4.19 (GPIO0); also elsewhere on the board
AD5941_1_RST: U4.22 (~RESET); also elsewhere on the board
AD5941_2_CS: U5.15 (~CS); also elsewhere on the board
AD5941_2_INT: U5.19 (GPIO0); also elsewhere on the board
AD5941_2_RST: U5.22 (~RESET); also elsewhere on the board
CE_BUS: J2.3, J3.3, J4.3, J5.3, J6.3, J7.3, J8.3, J9.3, U4.47 (CE0), U5.47 (CE0)
unnamed: J2.1, U4.39 (AIN0)
unnamed: J3.1, U4.38 (AIN1)
unnamed: J4.1, U4.37 (AIN2)
unnamed: J5.1, U4.36 (AIN3/BUF_VREF1V8)
unnamed: J6.1, U5.39 (AIN0)
unnamed: J7.1, U5.38 (AIN1)
unnamed: J8.1, U5.37 (AIN2)
unnamed: J9.1, U5.36 (AIN3/BUF_VREF1V8)
unnamed: C44.1, U4.14 (DVDD_REG_1V8)
unnamed: R13.1, U4.32 (RCAL0)
unnamed: R13.2, U4.33 (RCAL1)
unnamed: C43.1, U4.31 (VBIAS_CAP)
unnamed: C42.1, U4.43 (VREF_1V8)
unnamed: C41.1, U4.4 (VREF_2V5)
unnamed: C51.1, U5.14 (DVDD_REG_1V8)
unnamed: R14.1, U5.32 (RCAL0)
unnamed: R14.2, U5.33 (RCAL1)
unnamed: C48.1, U5.31 (VBIAS_CAP)
unnamed: C52.1, U5.43 (VREF_1V8)
unnamed: C50.1, U5.4 (VREF_2V5)
RE_BUS: J2.2, J3.2, J4.2, J5.2, J6.2, J7.2, J8.2, J9.2, U4.48 (RE0), U5.48 (RE0)
SPI1_MISO: U4.18 (MISO), U5.18 (MISO); also elsewhere on the board
SPI1_MOSI: U4.17 (MOSI), U5.17 (MOSI); also elsewhere on the board
SPI1_SCK: U4.16 (SCLK), U5.16 (SCLK); also elsewhere on the board

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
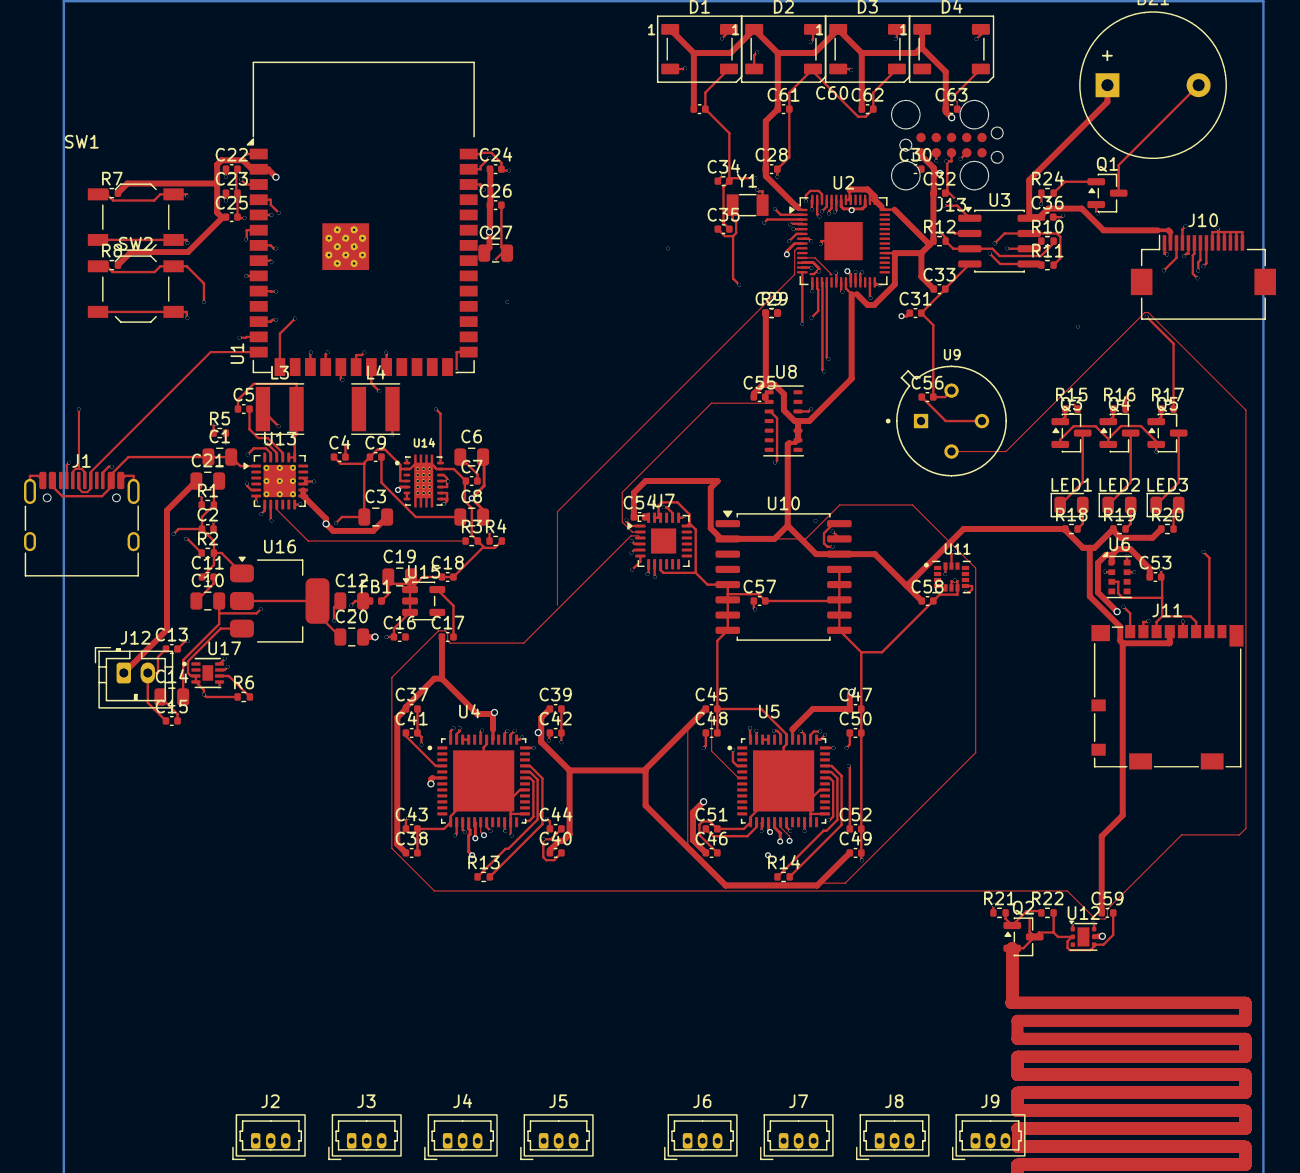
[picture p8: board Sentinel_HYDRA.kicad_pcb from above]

Board: 6 copper layers, 135 parts (0 on the bottom side), 123 nets.

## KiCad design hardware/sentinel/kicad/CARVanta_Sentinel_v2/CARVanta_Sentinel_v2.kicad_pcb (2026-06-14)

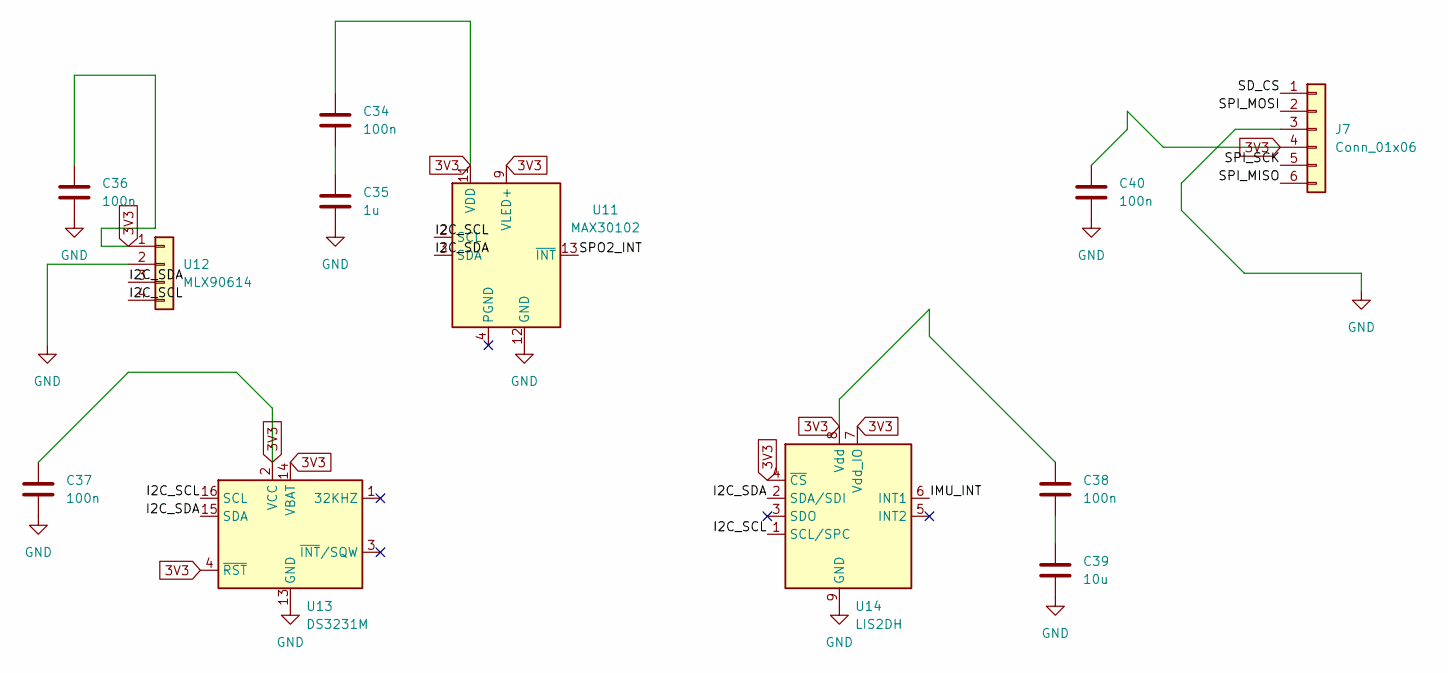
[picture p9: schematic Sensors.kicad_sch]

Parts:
C34, C36, C37, C38, C40: 100n; C_0805_2012Metric
C35: 1u; C_0805_2012Metric
C39: 10u; C_0805_2012Metric
J7: Conn_01x06; PinHeader_1x06_P2.54mm_Vertical
U11: MAX30102; Maxim_OLGA-14_3.3x5.6mm_P0.8mm
U12: MLX90614; TO-39-4
U13: DS3231M; SOIC-16W_7.5x10.3mm_P1.27mm
U14: LIS2DH; Bosch_LGA-14_3x2.5mm_P0.5mm

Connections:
3V3: C34.1, C35.2, C36.1, C36.2, C37.1, C37.2, C38.1, C39.2, C40.1, C40.2, J7.3, J7.4, U11.9 (VLED+), U11.10 (VLED+), U11.11 (VDD), U11.12 (GND), U12.1, U12.2, U13.2 (VCC), U13.4 (~RST), U13.5 (GND), U13.6 (GND), U13.7 (GND), U13.8 (GND), U13.9 (GND), U13.10 (GND), U13.11 (GND), U13.12 (GND), U13.13 (GND), U13.14 (VBAT), U14.4 (~CS), U14.7 (Vdd_IO), U14.8 (Vdd), U14.9 (GND), U14.10 (GND), U14.11 (GND), U14.12 (GND), U14.13 (GND), U14.14 (GND); also elsewhere on the board
/Sensors/I2C_SCL: U11.2 (SCL), U12.4, U13.16 (SCL), U14.1 (SCL/SPC)
/Sensors/I2C_SDA: U11.3 (SDA), U12.3, U13.15 (SDA), U14.2 (SDA/SDI)
/Sensors/IMU_INT: U14.6 (INT1)
/Sensors/SD_CS: J7.1
/Sensors/SPI_MISO: J7.6
/Sensors/SPI_MOSI: J7.2
/Sensors/SPI_SCK: J7.5
/Sensors/SPO2_INT: U11.13 (~INT)
unnamed: C34.2, C35.1
unnamed: C38.2, C39.1

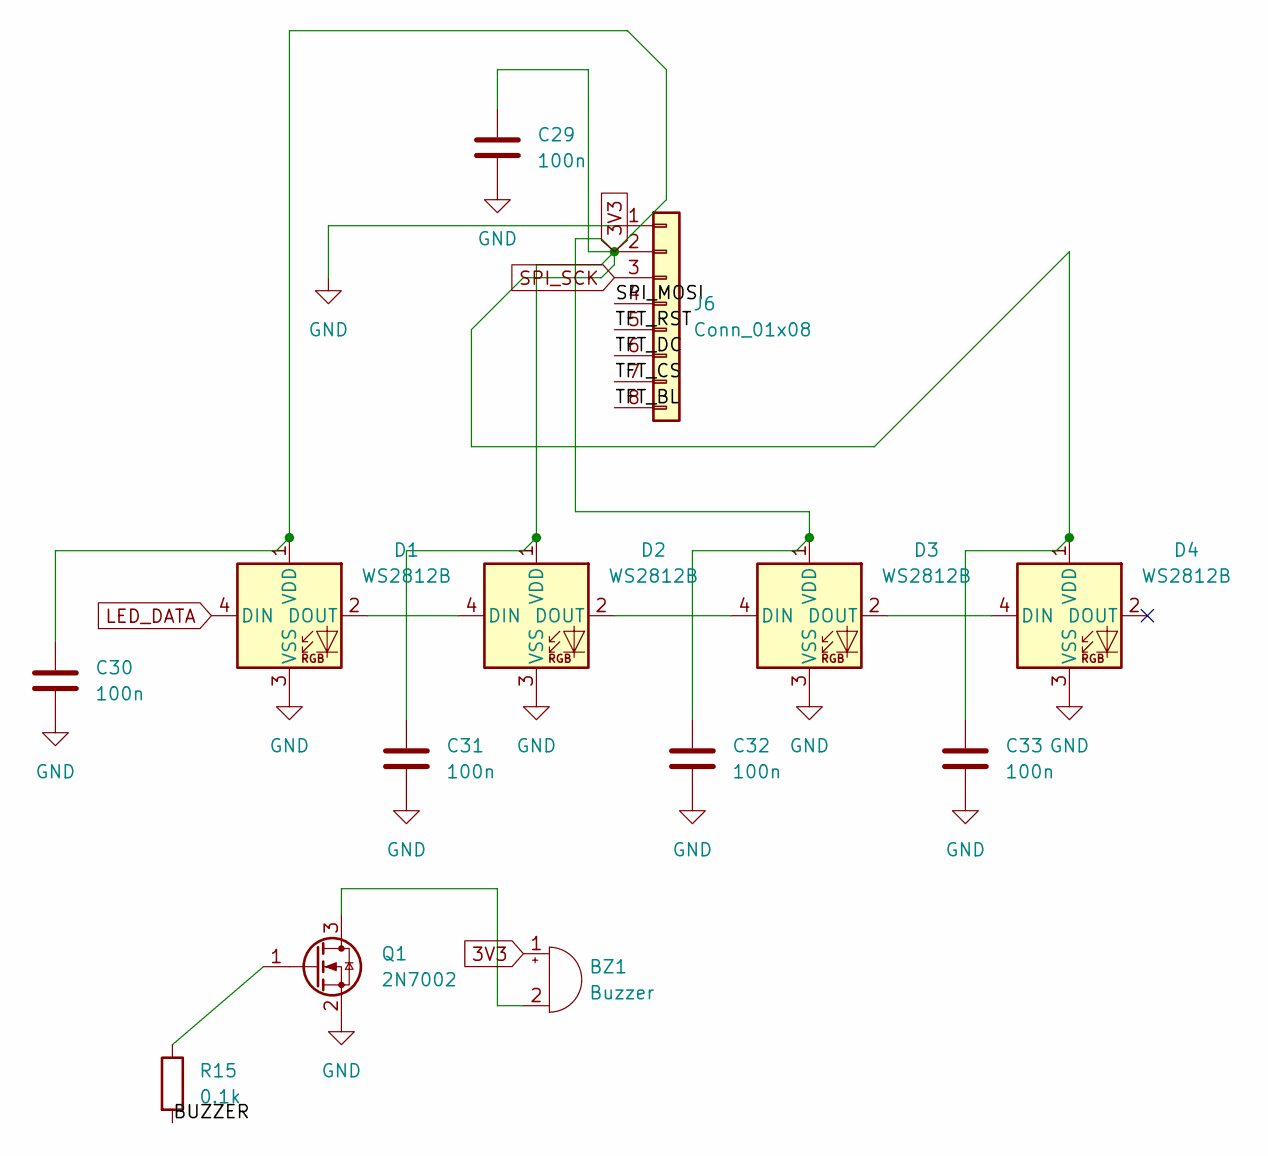
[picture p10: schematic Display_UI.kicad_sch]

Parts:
BZ1: Buzzer; Buzzer_12x9.5RM7.6
C29, C30, C31, C32, C33: 100n; C_0805_2012Metric
D1, D2, D3, D4: WS2812B; LED_WS2812B_PLCC4_5.0x5.0mm_P3.2mm
J6: Conn_01x08; PinHeader_1x08_P2.54mm_Vertical
Q1: 2N7002; SOT-23
R15: 0.1k; R_0402_1005Metric

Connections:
3V3: BZ1.1 (+), C29.1, C29.2, C30.1, C30.2, C31.1, C31.2, C32.1, C32.2, C33.1, C33.2, D1.1 (VDD), D1.3 (VSS), D2.1 (VDD), D2.3 (VSS), D3.1 (VDD), D3.3 (VSS), D4.1 (VDD), D4.3 (VSS), J6.1, J6.2, Q1.2 (S); also elsewhere on the board
/Display_UI/BUZZER: R15.2
/Display_UI/SPI_MOSI: J6.4
/Display_UI/TFT_BL: J6.8
/Display_UI/TFT_CS: J6.7
/Display_UI/TFT_DC: J6.6
/Display_UI/TFT_RST: J6.5
LED_DATA: D1.4 (DIN); also elsewhere on the board
unnamed: BZ1.2 (-), Q1.3 (D)
unnamed: D1.2 (DOUT), D2.4 (DIN)
unnamed: D2.2 (DOUT), D3.4 (DIN)
unnamed: D3.2 (DOUT), D4.4 (DIN)
unnamed: Q1.1 (G), R15.1
SPI_SCK: J6.3; also elsewhere on the board

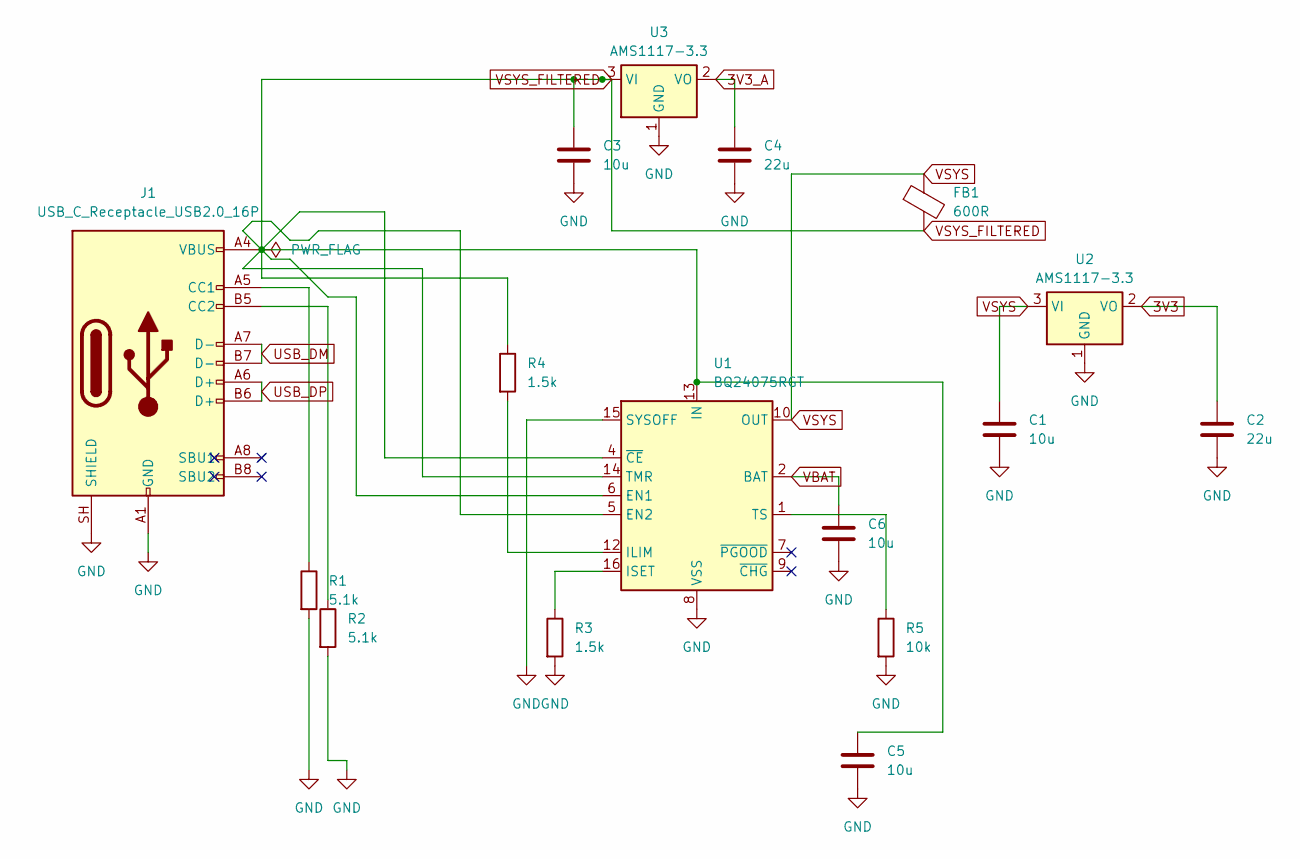
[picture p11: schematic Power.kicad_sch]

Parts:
C1, C3, C5, C6: 10u; C_0805_2012Metric
C2, C4: 22u; C_0805_2012Metric
FB1: 600R; L_0402_1005Metric
J1: USB_C_Receptacle_USB2.0_16P; USB_C_Receptacle_HCTL_HC-TYPE-C-16P-01A
R1, R2: 5.1k; R_0402_1005Metric
R3, R4: 1.5k; R_0402_1005Metric
R5: 10k; R_0402_1005Metric
U1: BQ24075RGT; VQFN-16-1EP_3x3mm_P0.5mm_EP1.8x1.8mm
U2, U3: AMS1117-3.3; SOT-223-3_TabPin2

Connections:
3V3: C1.2, C2.1, C2.2, C3.2, C4.2, C5.2, C6.2, J1.A1 (GND), J1.A12 (GND), J1.B1 (GND), J1.B12 (GND), J1.SH (SHIELD), R1.2, R2.2, R3.2, R5.2, U1.8 (VSS), U1.15 (SYSOFF), U1.17 (VSS), U2.1 (GND), U2.2 (VO), U3.1 (GND); also elsewhere on the board
3V3_A: C4.1, U3.2 (VO); also elsewhere on the board
unnamed: J1.A5 (CC1), R1.1
unnamed: J1.B5 (CC2), R2.1
unnamed: R4.2, U1.12 (ILIM)
unnamed: R3.1, U1.16 (ISET)
unnamed: R5.1, U1.1 (TS)
USB_DM: J1.A7 (D-), J1.B7 (D-); also elsewhere on the board
USB_DP: J1.A6 (D+), J1.B6 (D+); also elsewhere on the board
VBAT: C6.1, U1.2 (BAT), U1.3 (BAT); also elsewhere on the board
VSYS: C1.1, FB1.1, U1.10 (OUT), U1.11 (OUT), U2.3 (VI)
VSYS_FILTERED: C3.1, C5.1, FB1.2, J1.A4 (VBUS), J1.A9 (VBUS), J1.B4 (VBUS), J1.B9 (VBUS), R4.1, U1.4 (~CE), U1.5 (EN2), U1.6 (EN1), U1.13 (IN), U1.14 (TMR), U3.3 (VI)

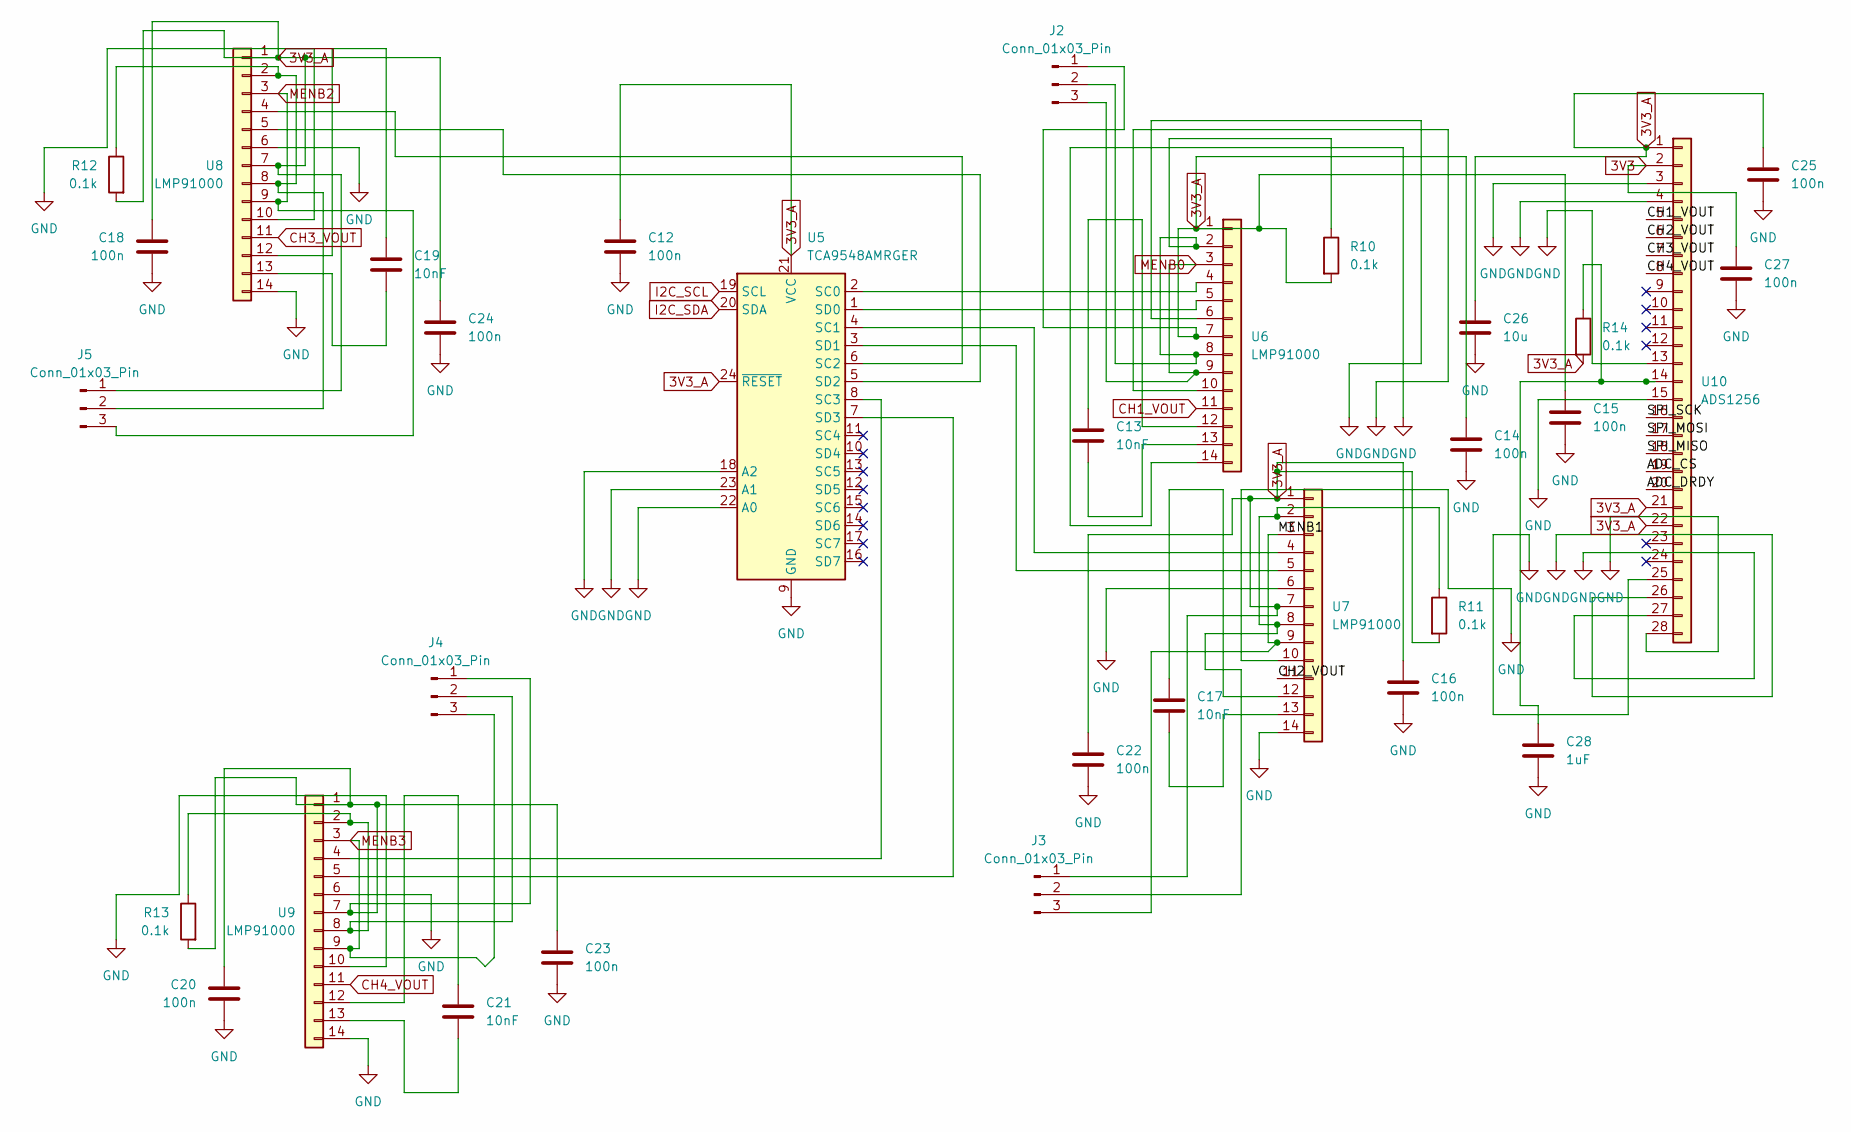
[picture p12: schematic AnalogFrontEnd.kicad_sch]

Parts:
C12, C14, C15, C16, C18, C20, C22, C23, C24, C25, C27: 100n; C_0805_2012Metric
C13, C17, C19, C21: 10nF; C_0805_2012Metric
C26: 10u; C_0805_2012Metric
C28: 1uF; C_0805_2012Metric
J2, J3, J4, J5: Conn_01x03_Pin; PinHeader_1x03_P2.54mm_Vertical
R10, R11, R12, R13, R14: 0.1k; R_0402_1005Metric
U5: TCA9548AMRGER; TSSOP-24_4.4x7.8mm_P0.65mm
U6, U7, U8, U9: LMP91000; TSSOP-14_4.4x5mm_P0.65mm
U10: ADS1256; TSSOP-28_4.4x9.7mm_P0.65mm

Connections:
3V3: C12.2, C14.2, C15.2, C16.2, C18.2, C20.2, C22.2, C23.2, C24.2, C25.2, C26.2, C27.1, C27.2, C28.2, U5.9 (GND), U5.18 (A2), U5.22 (A0), U5.23 (A1), U6.6, U6.10, U6.14, U7.6, U7.10, U7.14, U8.6, U8.10, U8.14, U9.6, U9.10, U9.14, U10.2, U10.3, U10.4, U10.13, U10.15, U10.25, U10.26, U10.27, U10.28; also elsewhere on the board
3V3_A: C12.1, C14.1, C15.1, C16.1, C18.1, C22.1, C24.1, C25.1, C26.1, J2.1, J3.1, J5.1, R10.2, R11.2, R12.2, R14.2, U5.21 (VCC), U5.24 (~RESET), U6.1, U6.7, U7.1, U7.7, U8.1, U8.7, U10.1, U10.21, U10.22; also elsewhere on the board
/AnalogFrontEnd/ADC_CS: U10.19
/AnalogFrontEnd/ADC_DRDY: U10.20
/AnalogFrontEnd/CH2_VOUT: U7.11, U10.6
/AnalogFrontEnd/MENB1: J3.3, U7.3, U7.9
/AnalogFrontEnd/SPI_MISO: U10.18
/AnalogFrontEnd/SPI_MOSI: U10.17
/AnalogFrontEnd/SPI_SCK: U10.16
CH1_VOUT: U6.11, U10.5
CH3_VOUT: U8.11, U10.7
CH4_VOUT: U9.11, U10.8
I2C_SCL: U5.19 (SCL); also elsewhere on the board
I2C_SDA: U5.20 (SDA); also elsewhere on the board
MENB0: J2.3, U6.3, U6.9; also elsewhere on the board
MENB2: J5.3, U8.3, U8.9; also elsewhere on the board
MENB3: J4.3, U9.3, U9.9; also elsewhere on the board
unnamed: J2.2, R10.1, U6.2, U6.8
unnamed: J3.2, R11.1, U7.2, U7.8
unnamed: C20.1, C23.1, J4.1, R13.2, U9.1, U9.7
unnamed: J4.2, R13.1, U9.2, U9.8
unnamed: J5.2, R12.1, U8.2, U8.8
unnamed: U5.2 (SC0), U6.4
unnamed: U5.4 (SC1), U7.4
unnamed: U5.6 (SC2), U8.4
unnamed: U5.8 (SC3), U9.4
unnamed: U5.1 (SD0), U6.5
unnamed: U5.3 (SD1), U7.5
unnamed: U5.5 (SD2), U8.5
unnamed: U5.7 (SD3), U9.5
unnamed: C13.1, U6.12
unnamed: C13.2, U6.13
unnamed: C17.1, U7.12
unnamed: C17.2, U7.13
unnamed: C19.1, U8.12
unnamed: C19.2, U8.13
unnamed: C21.1, U9.12
unnamed: C21.2, U9.13
unnamed: C28.1, R14.1, U10.14


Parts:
C7, C8, C10, C11: 100n; C_0805_2012Metric
C9: 22u; C_0805_2012Metric
R6, R7, R8, R9: 10k; R_0402_1005Metric
RN1: 100k; R_Array_Convex_2x0402
SW1, SW2: SW_Push; SW_SPST_PTS645Sx43SMTR92
U4: ESP32-S3-WROOM-1

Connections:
3V3: C7.1, C7.2, C8.1, C8.2, C9.1, C9.2, C10.2, C11.2, R6.2, R7.2, R8.1, R9.1, RN1.3, SW1.2, SW2.2, U4.1 (GND), U4.2 (3V3), U4.40 (GND), U4.41 (GND); also elsewhere on the board
ADC_CS: U4.38 (IO2)
ADC_DRDY: U4.39 (IO1)
BUZZER: U4.4 (IO4)
I2C_SCL: R7.1, U4.6 (IO6); also elsewhere on the board
I2C_SDA: R6.1, U4.5 (IO5); also elsewhere on the board
IMU_INT: U4.10 (IO17)
LED_DATA: U4.15 (IO3); also elsewhere on the board
MENB0: U4.28 (IO35); also elsewhere on the board
MENB1: U4.29 (IO36)
MENB2: U4.30 (IO37); also elsewhere on the board
MENB3: U4.31 (IO38); also elsewhere on the board
unnamed: C11.1, R8.2, SW1.1, U4.3 (EN)
unnamed: R9.2, SW2.1, U4.27 (IO0)
unnamed: C10.1, RN1.2, U4.8 (IO15)
SD_CS: U4.22 (IO14)
SPI_MISO: U4.21 (IO13)
SPI_MOSI: U4.19 (IO11)
SPI_SCK: U4.20 (IO12); also elsewhere on the board
SPO2_INT: U4.9 (IO16)
TFT_BL: U4.18 (IO10)
TFT_CS: U4.12 (IO8)
TFT_DC: U4.7 (IO7)
TFT_RST: U4.17 (IO9)
USB_DM: U4.13 (USB_D-); also elsewhere on the board
USB_DP: U4.14 (USB_D+); also elsewhere on the board
VBAT: RN1.1; also elsewhere on the board


Board: 6 copper layers, 100.0 x 100.0 mm, 86 parts (0 on the bottom side), 58 nets.

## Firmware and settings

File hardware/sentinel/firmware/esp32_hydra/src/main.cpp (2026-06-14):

/*
 * CARVanta Sentinel HYDRA — ESP32-S3 Main Firmware
 * ═══════════════════════════════════════════════════
 * Role: Brain MCU — WiFi/BLE, Display, Cloud Upload, AI Inference
 * Communicates with RP2040 co-processor via UART (JSON + CRC8)
 *
 * Architecture: FreeRTOS tasks on dual cores
 *   Core 0: WiFi, cloud upload, OTA
 *   Core 1: Sensors, display, measurement cycles
 */

#include <Arduino.h>
#include <Wire.h>
#include <SPI.h>

// ─── Project Headers ────────────────────────────────────
#include "config.h"
#include "pins.h"
#include "comms/rp2040_protocol.h"
#include "comms/cloud_client.h"
#include "sensors/i2c_mux.h"
#include "sensors/max30102.h"
#include "sensors/mlx90614.h"
#include "sensors/ds3231.h"
#include "sensors/lsm6dso.h"
#include "sensors/max17048.h"
#include "ui/display.h"
#include "ui/leds.h"
#include "ui/buzzer.h"
#include "storage/sd_logger.h"
#include "system/power_manager.h"
#include "system/watchdog.h"
#include "system/ota_updater.h"

// ─── Global Objects ─────────────────────────────────────
static RP2040Link    rp2040(Serial1);
static CloudClient   cloud;
static TCA9548A      mux(I2C_ADDR_TCA9548A);
static MAX30102      spo2Sensor(I2C_ADDR_MAX30102);
static MLX90614      irTemp(I2C_ADDR_MLX90614);
static DS3231        rtc(I2C_ADDR_DS3231);
static LSM6DSO       imu(I2C_ADDR_LSM6DSO);
static MAX17048      fuelGauge(I2C_ADDR_MAX17048);
static Display       display;
static StatusLEDs    leds;
static Buzzer        buzzer;
static SDLogger      sdLogger;
static PowerManager  power;
static Watchdog      wdt;
static OTAUpdater    ota;

// ─── Shared State ───────────────────────────────────────
static SensorReading currentReading;
static SemaphoreHandle_t readingMutex;
static volatile bool     measurementRequested = false;

// WiFi credentials (update these or load from NVS)
static const char* WIFI_SSID = "YOUR_SSID";
static const char* WIFI_PASS = "YOUR_PASSWORD";

// ─── Sensor Initialization ─────────────────────────────

static bool initSensors() {
    Serial.println("[INIT] Initializing sensors...");
    bool allOk = true;

    // I2C Mux
    if (mux.begin(Wire)) {
        Serial.println("[INIT] TCA9548A mux: OK");
    } else {
        Serial.println("[INIT] TCA9548A mux: FAILED");
        allOk = false;
    }

    // MAX30102 (Mux Ch0)
    mux.selectChannel(MUX_CH_MAX30102);
    if (spo2Sensor.begin(Wire)) {
        Serial.println("[INIT] MAX30102 SpO2: OK");
    } else {
        Serial.println("[INIT] MAX30102 SpO2: FAILED");
        allOk = false;
    }

    // MLX90614 (Mux Ch1)
    mux.selectChannel(MUX_CH_MLX90614);
    if (irTemp.begin(Wire)) {
        Serial.println("[INIT] MLX90614 IR temp: OK");
    } else {
        Serial.println("[INIT] MLX90614 IR temp: FAILED");
        allOk = false;
    }

    // DS3231 (Mux Ch2)
    mux.selectChannel(MUX_CH_DS3231);
    if (rtc.begin(Wire)) {
        Serial.println("[INIT] DS3231 RTC: OK");
    } else {
        Serial.println("[INIT] DS3231 RTC: FAILED");
        allOk = false;
    }

    // LSM6DSO (Mux Ch3)
    mux.selectChannel(MUX_CH_LSM6DSO);
    if (imu.begin(Wire)) {
        Serial.println("[INIT] LSM6DSO IMU: OK");
    } else {
        Serial.println("[INIT] LSM6DSO IMU: FAILED");
        allOk = false;
    }

    mux.disableAll();

    // MAX17048 (direct on I2C, no mux)
    if (fuelGauge.begin(Wire)) {
        Serial.println("[INIT] MAX17048 fuel gauge: OK");
    } else {
        Serial.println("[INIT] MAX17048 fuel gauge: FAILED");
        allOk = false;
    }

    return allOk;
}

// ─── Measurement Cycle ─────────────────────────────────

static void runMeasurementCycle() {
    Serial.println("[MEAS] Starting measurement cycle...");
    leds.setMode(LEDMode::MEASURING);

    xSemaphoreTake(readingMutex, portMAX_DELAY);

    // 1. Electrochemical sweep (RP2040)
    display.showMeasuring("Electrochemical");
    currentReading.echem_valid = rp2040.requestEchem(currentReading.echem_channels);

    // 2. EIS (RP2040)
    display.showMeasuring("Impedance");
    currentReading.eis_valid = rp2040.requestEIS(
        currentReading.eis_impedance, currentReading.eis_phase);

    // 3. Spectral (RP2040)
    display.showMeasuring("Spectral");
    currentReading.spectral_valid = rp2040.requestSpectral(currentReading.spectral);

    // 4. Thermal (RP2040)
    display.showMeasuring("Thermal");
    currentReading.thermal_valid = rp2040.requestThermal(
        &currentReading.precision_temp, &currentReading.heater_temp);

    // 5. SpO2 + Heart Rate (direct I2C via mux)
    display.showMeasuring("Vitals");
    mux.selectChannel(MUX_CH_MAX30102);
    currentReading.vitals_valid = spo2Sensor.readSpO2(
        &currentReading.spo2, &currentReading.heart_rate, 4000);

    // 6. IR Temperature
    mux.selectChannel(MUX_CH_MLX90614);
    currentReading.ir_object_temp = irTemp.readObjectTemp();
    currentReading.ir_ambient_temp = irTemp.readAmbientTemp();

    // 7. RTC Timestamp
    mux.selectChannel(MUX_CH_DS3231);
    DateTime dt = rtc.getDateTime();
    currentReading.timestamp = rtc.getEpoch();
    currentReading.year   = dt.year - 2000;
    currentReading.month  = dt.month;
    currentReading.day    = dt.day;
    currentReading.hour   = dt.hour;
    currentReading.minute = dt.minute;
    currentReading.second = dt.second;

    // 8. IMU
    mux.selectChannel(MUX_CH_LSM6DSO);
    imu.readAccel(currentReading.accel[0], currentReading.accel[1], currentReading.accel[2]);
    imu.readGyro(currentReading.gyro[0], currentReading.gyro[1], currentReading.gyro[2]);
    currentReading.motion_valid = true;

    mux.disableAll();

    // 9. Battery
    currentReading.battery_soc     = fuelGauge.getSOC();
    currentReading.battery_voltage = fuelGauge.getVoltage();
    currentReading.battery_rate    = fuelGauge.getRate();

    xSemaphoreGive(readingMutex);

    // 10. Display results
    display.showDashboard(currentReading);

    // 11. Log to SD
    if (sdLogger.isReady()) {
        sdLogger.logReading(currentReading);
    }

    // 12. Upload to cloud (done in cloud task)

    leds.setMode(LEDMode::SUCCESS);
    buzzer.successBeep();
    Serial.println("[MEAS] Measurement cycle complete.");
}

// ─── FreeRTOS Tasks ─────────────────────────────────────

// Task: Measurement + Display (Core 1)
static void taskMeasurement(void* param) {
    TickType_t lastWake = xTaskGetTickCount();

    for (;;) {
        wdt.feed();
        runMeasurementCycle();
        vTaskDelayUntil(&lastWake, pdMS_TO_TICKS(MEASUREMENT_INTERVAL_MS));
    }
}

// Task: Cloud Upload (Core 0)
static void taskCloudUpload(void* param) {
    TickType_t lastUpload = xTaskGetTickCount();

    for (;;) {
        vTaskDelayUntil(&lastUpload, pdMS_TO_TICKS(CLOUD_UPLOAD_INTERVAL_MS));

        if (!cloud.isConnected()) {
            cloud.connectWiFi();
        }

        xSemaphoreTake(readingMutex, portMAX_DELAY);
        SensorReading snapshot = currentReading;
        xSemaphoreGive(readingMutex);

        if (cloud.uploadReading(snapshot)) {
            Serial.println("[CLOUD] Upload successful");
        } else {
            Serial.println("[CLOUD] Upload failed");
        }
    }
}

// Task: UI Updates (Core 1)
static void taskUI(void* param) {
    for (;;) {
        leds.update();
        buzzer.update();
        ota.handle();

        // Check battery
        float soc = fuelGauge.getSOC();
        if (soc < BATTERY_LOW_THRESHOLD && soc > BATTERY_CRITICAL) {
            leds.setMode(LEDMode::LOW_BATTERY);
            display.showError("LOW BATTERY!");
        }
        power.checkCriticalBattery(soc);

        vTaskDelay(pdMS_TO_TICKS(33));  // ~30fps
    }
}

// ─── SETUP ──────────────────────────────────────────────

void setup() {
    Serial.begin(USB_SERIAL_BAUD);
    delay(500);
    Serial.println("\n═══════════════════════════════════════");
    Serial.println("  CARVanta Sentinel HYDRA v" FW_VERSION);
    Serial.println("  Multimodal Diagnostic Engine");
    Serial.println("═══════════════════════════════════════\n");

    // Create mutex
    readingMutex = xSemaphoreCreateMutex();

    // Initialize subsystems
    Serial.println("[INIT] Peripherals...");

    // UART to RP2040
    rp2040.begin(RP2040_BAUD_RATE, PIN_UART_RX, PIN_UART_TX);
    Serial.println("[INIT] RP2040 UART: OK");

    // I2C
    Wire.begin(PIN_I2C_SDA, PIN_I2C_SCL);
    Wire.setClock(I2C_CLOCK_HZ);
    Serial.println("[INIT] I2C bus: OK");

    // SPI (for SD card — TFT uses its own SPI in TFT_eSPI)
    SPI.begin(PIN_SPI0_SCK, PIN_SPI0_MISO, PIN_SPI0_MOSI);

    // Display
    display.begin();
    display.showSplash();
    Serial.println("[INIT] TFT display: OK");

    // LEDs
    leds.begin();
    leds.setMode(LEDMode::IDLE);
    Serial.println("[INIT] WS2812B LEDs: OK");

    // Buzzer
    buzzer.begin();
    Serial.println("[INIT] Buzzer: OK");

    // Power manager
    power.begin();
    Serial.println("[INIT] Power manager: OK");

    // SD Card
    if (sdLogger.begin(PIN_SD_CS)) {
        Serial.println("[INIT] SD card: OK");
    } else {
        Serial.println("[INIT] SD card: NOT FOUND (logging disabled)");
    }

    // Sensors (via I2C mux)
    bool sensorsOk = initSensors();

    // WiFi
    cloud.begin(WIFI_SSID, WIFI_PASS);
    if (cloud.connectWiFi()) {
        Serial.printf("[INIT] WiFi connected: %s\n", WiFi.localIP().toString().c_str());
        display.showWiFiStatus(true, WiFi.localIP().toString().c_str());
    } else {
        Serial.println("[INIT] WiFi: FAILED (offline mode)");
        display.showWiFiStatus(false);
    }

    // OTA
    ota.begin();
    Serial.println("[INIT] OTA updater: OK");

    // Watchdog
    wdt.begin();
    Serial.println("[INIT] Watchdog: OK");

    // Boot chime
    buzzer.bootChime();

    delay(2000);
    Serial.println("\n[HYDRA] ═══ System Ready ═══\n");

    // ─── Launch FreeRTOS Tasks ──────────────────────────
    xTaskCreatePinnedToCore(taskMeasurement, "Measure", 8192, NULL, 2, NULL, 1);
    xTaskCreatePinnedToCore(taskCloudUpload, "Cloud",   4096, NULL, 1, NULL, 0);
    xTaskCreatePinnedToCore(taskUI,          "UI",      4096, NULL, 1, NULL, 1);
}

// ─── LOOP (unused — all work done in FreeRTOS tasks) ────

void loop() {
    vTaskDelay(pdMS_TO_TICKS(1000));
}

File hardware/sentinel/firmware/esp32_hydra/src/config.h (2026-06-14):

/*
 * CARVanta Sentinel HYDRA — ESP32-S3 Configuration
 * System constants, I2C addresses, timing, feature flags
 */

#pragma once

#include <cstdint>

// ─── VERSION ────────────────────────────────────────────
#define FW_VERSION          "2.0.0"
#define FW_BUILD_DATE       __DATE__
#define DEVICE_ID_PREFIX    "HYDRA"

// ─── FEATURE FLAGS ──────────────────────────────────────
#define ENABLE_OTA          1
#define ENABLE_CLOUD        1
#define ENABLE_SD_LOGGING   1
#define ENABLE_DISPLAY      1
#define ENABLE_WATCHDOG     1

// ─── COMMUNICATION ──────────────────────────────────────
#define RP2040_BAUD_RATE    921600
#define USB_SERIAL_BAUD     115200
#define I2C_CLOCK_HZ        400000

// ─── I2C ADDRESSES ──────────────────────────────────────
#define I2C_ADDR_TCA9548A   0x70  // I2C Mux
#define I2C_ADDR_MAX30102   0x57  // SpO2 (Mux Ch0)
#define I2C_ADDR_MLX90614   0x5A  // IR Temp (Mux Ch1)
#define I2C_ADDR_DS3231     0x68  // RTC (Mux Ch2)
#define I2C_ADDR_LSM6DSO    0x6A  // IMU (Mux Ch3)
#define I2C_ADDR_MAX17048   0x36  // Fuel Gauge (direct, no mux)
#define I2C_ADDR_BQ25895    0x6B  // Charger (direct, no mux)

// ─── TCA9548A MUX CHANNEL MAP ───────────────────────────
#define MUX_CH_MAX30102     0
#define MUX_CH_MLX90614     1
#define MUX_CH_DS3231       2
#define MUX_CH_LSM6DSO      3
// Channels 4–7 spare

// ─── TIMING ─────────────────────────────────────────────
#define MEASUREMENT_INTERVAL_MS     30000   // 30 seconds
#define DISPLAY_REFRESH_MS          1000    // 1 second
#define CLOUD_UPLOAD_INTERVAL_MS    60000   // 1 minute
#define WIFI_CONNECT_TIMEOUT_MS     10000   // 10 seconds
#define RP2040_CMD_TIMEOUT_MS       5000    // 5 second command timeout
#define RP2040_RETRY_COUNT          3       // retry failed commands
#define WATCHDOG_TIMEOUT_S          30      // 30 second WDT

// ─── CLOUD ──────────────────────────────────────────────
#define API_ENDPOINT        "https://carvanta-api.up.railway.app/api/v1/sentinel/upload"
#define OTA_CHECK_ENDPOINT  "https://carvanta-api.up.railway.app/api/v1/sentinel/ota"
#define CLOUD_RETRY_MAX     5
#define CLOUD_BACKOFF_BASE_MS   1000  // exponential backoff base

// ─── DISPLAY ────────────────────────────────────────────
#define TFT_WIDTH           240
#define TFT_HEIGHT          320
#define TFT_BACKLIGHT_PWM   200  // 0–255

// ─── BATTERY ────────────────────────────────────────────
#define BATTERY_LOW_THRESHOLD   15.0f  // % SOC
#define BATTERY_CRITICAL        5.0f   // % SOC → deep sleep

// ─── SD CARD ────────────────────────────────────────────
#define SD_LOG_DIR          "/hydra_logs"
#define SD_MAX_FILE_SIZE    (5 * 1024 * 1024)  // 5MB per file

// ─── SENSOR DATA STRUCTURE ──────────────────────────────
struct SensorReading {
    // Electrochemical (from RP2040 via UART)
    float echem_channels[8];     // AD5941 CV current (µA)
    float eis_impedance[8];      // EIS impedance (Ω)
    float eis_phase[8];          // EIS phase (degrees)

    // Spectral (from RP2040 via UART)
    float spectral[11];          // AS7341 11-channel (counts)

    // Thermal (from RP2040 via UART)
    float precision_temp;        // TMP117 (°C)
    float heater_temp;           // Heater zone (°C)

    // Vitals (read directly via I2C mux)
    float spo2;                  // MAX30102 (%)
    float heart_rate;            // MAX30102 (BPM)
    float ir_object_temp;        // MLX90614 object (°C)
    float ir_ambient_temp;       // MLX90614 ambient (°C)

    // Motion (read directly via I2C mux)
    float accel[3];              // LSM6DSO (g)
    float gyro[3];               // LSM6DSO (dps)

    // Power
    float battery_soc;           // MAX17048 (%)
    float battery_voltage;       // MAX17048 (V)
    float battery_rate;          // MAX17048 (%/hr)

    // Timestamp
    uint32_t timestamp;          // DS3231 epoch
    uint8_t  year, month, day;
    uint8_t  hour, minute, second;

    // Flags
    bool     echem_valid;
    bool     eis_valid;
    bool     spectral_valid;
    bool     thermal_valid;
    bool     vitals_valid;
    bool     motion_valid;
};

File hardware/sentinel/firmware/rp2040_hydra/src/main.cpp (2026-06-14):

/*
 * CARVanta Sentinel HYDRA — RP2040 Co-Processor Firmware
 * ═══════════════════════════════════════════════════════
 * Role: Real-time sensor control — AD5941 electrochemistry,
 *       AS7341 spectral, TMP117 thermal, heater PID
 * Communicates with ESP32 via UART (JSON + CRC8)
 *
 * Architecture: Dual-core
 *   Core 0: Command processing, sensor reads
 *   Core 1: Heater PID loop (real-time, 10Hz)
 */

#include <Arduino.h>
#include <SPI.h>
#include <Wire.h>

// ─── Project Headers ────────────────────────────────────
#include "config.h"
#include "pins.h"
#include "drivers/ad5941.h"
#include "drivers/as7341.h"
#include "drivers/tmp117.h"
#include "control/heater_pid.h"
#include "control/led_driver.h"
#include "comms/esp32_protocol.h"

// ─── Global Objects ─────────────────────────────────────
static AD5941        afe1(PIN_AD5941_1_CS, PIN_AD5941_1_RST, PIN_AD5941_1_INT);
static AD5941        afe2(PIN_AD5941_2_CS, PIN_AD5941_2_RST, PIN_AD5941_2_INT);
static AS7341        spectral;
static TMP117        tempSensor;
static HeaterPID     heater;
static LEDDriver     excitationLEDs;
static ESP32Protocol esp32(Serial1);

// ─── Hardware Status Flags ──────────────────────────────
static bool afe1_ok     = false;
static bool afe2_ok     = false;
static bool spectral_ok = false;
static bool temp_ok     = false;

// ─── Command Processing ────────────────────────────────

static void handleRunEchem() {
    StaticJsonDocument<512> data;
    JsonArray ch = data.createNestedArray("channels");

    for (int i = 0; i < 4; i++) {
        float val = afe1_ok ? afe1.runCV(i) : 0.0f;
        ch.add(val);
    }
    for (int i = 0; i < 4; i++) {
        float val = afe2_ok ? afe2.runCV(i) : 0.0f;
        ch.add(val);
    }

    esp32.sendResponse("echem", data);
    Serial.println("[CMD] run_echem complete");
}

static void handleRunEIS() {
    StaticJsonDocument<512> data;
    JsonArray imp = data.createNestedArray("impedance");
    JsonArray pha = data.createNestedArray("phase");

    for (int i = 0; i < 4; i++) {
        float z = 0, p = 0;
        if (afe1_ok) afe1.runEIS(i, 1000.0f, &z, &p);
        imp.add(z);
        pha.add(p);
    }
    for (int i = 0; i < 4; i++) {
        float z = 0, p = 0;
        if (afe2_ok) afe2.runEIS(i, 1000.0f, &z, &p);
        imp.add(z);
        pha.add(p);
    }

    esp32.sendResponse("eis", data);
    Serial.println("[CMD] run_eis complete");
}

static void handleReadSpectral() {
    // Turn on white LED for illumination
    excitationLEDs.enable(ExcitationLED::WHITE);
    delay(50);  // Stabilize

    float channels[11] = {0};
    if (spectral_ok) {
        spectral.readAllChannels(channels);
    }

    excitationLEDs.disable(ExcitationLED::WHITE);

    StaticJsonDocument<512> data;
    JsonArray ch = data.createNestedArray("channels");
    for (int i = 0; i < 11; i++) ch.add(channels[i]);

    esp32.sendResponse("spectral", data);
    Serial.println("[CMD] read_spectral complete");
}

static void handleReadThermal() {
    float temp = temp_ok ? tempSensor.readTemperature() : -999.0f;

    StaticJsonDocument<128> data;
    data["temp"]   = temp;
    data["heater"] = heater.isEnabled() ? heater.getTarget() : 0.0f;

    esp32.sendResponse("thermal", data);
}

static void handleHeaterOn(JsonDocument& cmd) {
    float target = cmd["params"]["temp"] | HEATER_TARGET_TEMP;
    heater.enable(target);
    esp32.sendAck("heater_on");
}

static void handleHeaterOff() {
    heater.disable();
    esp32.sendAck("heater_off");
}

static void handleLED(const char* color, bool on) {
    if (strcmp(color, "led_uv") == 0) {
        if (on) excitationLEDs.enable(ExcitationLED::UV);
        else    excitationLEDs.disable(ExcitationLED::UV);
    } else if (strcmp(color, "led_blue") == 0) {
        if (on) excitationLEDs.enable(ExcitationLED::BLUE);
        else    excitationLEDs.disable(ExcitationLED::BLUE);
    }
    esp32.sendAck(color);
}

static void processCommand(JsonDocument& doc) {
    const char* cmd = doc["cmd"];
    if (!cmd) return;

    if      (strcmp(cmd, "run_echem") == 0)     handleRunEchem();
    else if (strcmp(cmd, "run_eis") == 0)        handleRunEIS();
    else if (strcmp(cmd, "read_spectral") == 0)  handleReadSpectral();
    else if (strcmp(cmd, "read_thermal") == 0)   handleReadThermal();
    else if (strcmp(cmd, "heater_on") == 0)      handleHeaterOn(doc);
    else if (strcmp(cmd, "heater_off") == 0)     handleHeaterOff();
    else if (strncmp(cmd, "led_", 4) == 0) {
        bool on = doc["params"]["on"] | false;
        handleLED(cmd, on);
    }
    else {
        Serial.printf("[CMD] Unknown command: %s\n", cmd);
        esp32.sendError(cmd, "unknown_command");
    }
}

// ─── Core 1: PID Loop (runs on second core) ────────────

static volatile bool core1_ready = false;

void setup1() {
    // Core 1 setup — nothing extra needed
    core1_ready = true;
    Serial.println("[CORE1] PID loop ready");
}

void loop1() {
    // Real-time heater PID at 10Hz
    static unsigned long lastPID = 0;

    if (millis() - lastPID >= HEATER_PID_INTERVAL_MS) {
        lastPID = millis();

        if (heater.isEnabled() && temp_ok) {
            float temp = tempSensor.readTemperature();
            heater.update(temp);
        }
    }

    // LED safety timeout check
    excitationLEDs.update();

    delay(10);
}

// ─── Core 0: Setup ─────────────────────────────────────
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

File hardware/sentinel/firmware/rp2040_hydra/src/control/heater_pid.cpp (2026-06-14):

/*
 * Heater PID Controller — Implementation
 */

#include "heater_pid.h"

void HeaterPID::begin() {
    pinMode(PIN_HEATER_PWM, OUTPUT);
    analogWrite(PIN_HEATER_PWM, 0);
    _enabled = false;
}

void HeaterPID::enable(float targetTemp) {
    _targetTemp = targetTemp;
    _integral = 0;
    _prevError = 0;
    _enabled = true;
    Serial.printf("[PID] Heater ON, target=%.1f°C\n", targetTemp);
}

void HeaterPID::disable() {
    _enabled = false;
    _integral = 0;
    _prevError = 0;
    _output = 0;
    analogWrite(PIN_HEATER_PWM, 0);
    Serial.println("[PID] Heater OFF");
}

void HeaterPID::setTuning(float kp, float ki, float kd) {
    _kp = kp;
    _ki = ki;
    _kd = kd;
}

void HeaterPID::setMaxDuty(uint8_t maxDuty) {
    _maxDuty = maxDuty;
}

void HeaterPID::update(float currentTemp) {
    if (!_enabled) {
        analogWrite(PIN_HEATER_PWM, 0);
        return;
    }

    // ─── Safety Check: Over-temperature shutdown ────────
    if (currentTemp > HEATER_MAX_TEMP) {
        Serial.printf("[PID] OVER-TEMP SHUTDOWN! %.1f°C > %.1f°C limit\n",
                      currentTemp, HEATER_MAX_TEMP);
        disable();
        return;
    }

    // ─── PID Calculation ────────────────────────────────
    float dt = HEATER_PID_INTERVAL_MS / 1000.0f;  // seconds

    float error = _targetTemp - currentTemp;

    // Proportional
    float pTerm = _kp * error;

    // Integral with anti-windup clamping
    _integral += error * dt;
    if (_integral > 100.0f)  _integral = 100.0f;
    if (_integral < -100.0f) _integral = -100.0f;
    float iTerm = _ki * _integral;

    // Derivative
    float derivative = (error - _prevError) / dt;
    float dTerm = _kd * derivative;
    _prevError = error;

    // Output
    _output = pTerm + iTerm + dTerm;

    // Clamp output to valid PWM range
    if (_output < 0.0f) _output = 0.0f;
    if (_output > (float)_maxDuty) _output = (float)_maxDuty;

    analogWrite(PIN_HEATER_PWM, (int)_output);
}

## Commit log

2026-03-23 git push -u origin main --forceInitial commit
    [biomarker_database.csv]
2026-03-23 Removed sensitive files
    [biomarker_database.csv]
2026-03-26 chore: stage pending changes
2026-03-26 security: remove hardcoded secrets, use env_file in docker-compose
    - auth.py: removed hardcoded JWT_SECRET and PASSWORD_SALT fallbacks
    - docker-compose.dev.yml: replaced inline keys with env_file reference
    - .env.example: added JWT_SECRET, PASSWORD_SALT, SMTP placeholders
    [auth.py]
2026-03-26 fix: auto-verify accounts in dev mode (SMTP blocked by network)
    [auth.py]
2026-03-26 fix: skip email verification in dev mode - accounts auto-verified
    [auth_router.py]
2026-04-24 Add biomarker_database.csv for Render deployment
    [biomarker_database.csv]
2026-04-24 Use nixpacks for Railway: lighter deps, no Docker
2026-04-24 Add data cache files for faster API startup on Railway
2026-04-25 Add Deep Learning Suite: GNN, Transformer, MLP, VAE, LSTM — 5 neural networks in pure NumPy with API + frontend
2026-04-25 Wire LLM ai_insight display to all major frontend pages: SingleAnalysis, Comparison, DigitalTwin, NLPSearch, ResearchCopilot + add ai_insight to batch_score API
2026-04-25 Add Model Validation & Certification suite: 5-fold CV, FDA ground-truth, robustness testing, statistical significance, ISO/IEC 25010 certification report with LLM interpretation
2026-04-25 Railway deployment config + comprehensive README + deploy requirements with xgboost/scipy/httpx
2026-04-25 Disable render.yaml blueprint to prevent duplicate Railway service
2026-04-25 Fix Railway build: use python3 -m pip instead of bare pip
2026-06-14 feat: complete Sentinel HYDRA firmware rewrite + Render deployment config
    - ESP32-S3: 34 firmware files (sensors, comms, UI, storage, system)
    - RP2040: 16 firmware files (AD5941 AFE, AS7341 spectral, TMP117, PID heater)
    - FreeRTOS dual-core architecture with CRC8 UART protocol
    - Updated PITCH.md with current project metrics (117K lines)
    - Added Render deployment config (render.yaml)
    - Updated vercel.json for backend proxy
    [AnalogFrontEnd.kicad_sch, CARVanta_Sentinel_v2.kicad_pcb, CARVanta_Sentinel_v2.kicad_sch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]
2026-06-15 feat: add Sentinel HYDRA Gerber manufacturing package + documentation overhaul
    - Generate production Gerbers (6-layer, all copper + mask + silk + paste + edge)
    - Generate Excellon drill files (PTH + NPTH separated)
    - Create manufacturing-ready ZIP for JLCPCB/PCBWay
    - Rewrite README with hardware section and updated architecture
    - Full Contributor Covenant v2.1 Code of Conduct
    - Comprehensive contributing guide (software + hardware + firmware)
    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
    [Sentinel_HYDRA-B_Fab.gbr, Sentinel_HYDRA-B_Mask.gbs, Sentinel_HYDRA-B_Paste.gbp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]
2026-06-15 Update device dimensions from 95mm to 100mm
2026-08-04 Implemented dashboard improvements
    [biomarker_database.carback.csv, biomarker_database.csv]
2026-08-04 Implemented dashboard improvements (#44)
    [biomarker_database.carback.csv, biomarker_database.csv]
